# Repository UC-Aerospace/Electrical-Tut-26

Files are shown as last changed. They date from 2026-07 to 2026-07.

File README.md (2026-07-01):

# 2026 Avionics tutorial example boards!!
Here's where you'll find basic examples of a flight computer board using the RP2350 microcontroller. 

We have two different example sizes.  
  
(50mm x 50mm) This shows it's possible to design a 2-layer 50mm x 50mm board to fit the minimum rocket tube diameter of 50mm. Made by Grayson. This is the one we have ordered and will be avalible to pass around.  
  
~~(66mm x 66mm) This 2-layer example board is slightly bigger but small enough to fit in an L2 rocket. Made by Kaden.~~  
Unfortunatly this board has some issues at the moment, we might look into fixing it. Left for now as it shows a different general approach.

> [!NOTE]
> While making a 2-layer 50mm x 50mm board is possible, routing something this small can be quite a puzzle especially to do nicely. If you do target 50x50 we would reccomend a 4-layer board. Otherwise, we'd suggest something either 66x66mm or 88x88mm.

> [!CAUTION]
> We are not experts and are still all learning a lot ourselves. As such some of these designs may be suboptimal, don't take them as best practice. If you see an issue with any of the boards, or even just think you do, feel free to create an issue so we can all learn.

## Templates

These are barebones files to use as a starting point, and very simply include a board outline with holes that will match with our sleds, the RP2350 footprint and the Sense module footprint. Avalible in 50x50, 66x66 and 88x88 to modify as you wish.

## Resources / Datasheets
**_Please look_** at the datasheets for any major components you plan to use, e.g. (Voltage regulator, RP2350, Flash chip, Screen, LEDs, USB-C connector, etc..) They provide the information necessary to integrate them with your project and if any extra components are needed to work correctly.

The Raspberry Pi Foundation has provided a massive amount of technical information for the RP2350 microcontroller we use, so I'd suggest reviewing their datasheets to help build your boards!

[RP2350 Datasheet](https://datasheets.raspberrypi.com/rp2350/rp2350-datasheet.pdf)  
[RP2350 Hardware design examples](https://datasheets.raspberrypi.com/rp2350/hardware-design-with-rp2350.pdf)  
[Raspberry Pi Pico 2 datasheet](https://datasheets.raspberrypi.com/pico/pico-2-datasheet.pdf)
  
Also take a look at the sensor package used which we have got assembled for you:
[MicroSense](https://github.com/UC-Aerospace/Sense)

If you have any questions about the example board, then come talk to me!  
Happy making! :3


  
^ Demo flight computer, we will have a few to pass around.

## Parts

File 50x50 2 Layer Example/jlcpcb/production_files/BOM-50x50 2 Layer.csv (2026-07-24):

Comment | Designator | Footprint | LCSC | Quantity
0.25A | F1 | Fuse_0603_1608Metric | C151137 | 1
100 | R21,R22,R23 | C_0603_1608Metric_Pad1.08x0.95mm_HandSolder | C22775 | 3
100n | C1,C10,C13,C16,C17,C18,C19,C20,C21,C22,C23,C4,C5,C9 | C_0603_1608Metric_Pad1.08x0.95mm_HandSolder | C14663 | 14
10k | R7,R8 | R_0603_1608Metric_Pad0.98x0.95mm_HandSolder | C25804 | 2
10u | C24 | C_0805_2012Metric | C15850 | 1
12MHz | Y1 | Crystal_SMD_3225-4Pin_3.2x2.5mm_HandSoldering | C20625731 | 1
15p | C7,C8 | C_0603_1608Metric_Pad1.08x0.95mm_HandSolder | C1644 | 2
1k | R10,R13,R26,R27,R9 | R_0603_1608Metric_Pad0.98x0.95mm_HandSolder | C21190 | 5
1u | C2 | C_0603_1608Metric_Pad1.08x0.95mm_HandSolder | C15849 | 1
22u | C3,C6 | C_0805_2012Metric | C45783 | 2
27 | R14,R15 | R_0603_1608Metric_Pad0.98x0.95mm_HandSolder | C25190 | 2
3.3u | L1 | IND-SMD_L2.0-W1.6_AOTA-B201610S3R3-101-T | C42411119 | 1
33 | R12 | R_0603_1608Metric_Pad0.98x0.95mm_HandSolder | C23140 | 1
390 | R11 | C_0603_1608Metric_Pad1.08x0.95mm_HandSolder | C23151 | 1
4.7u | C11,C12,C14,C15 | C_0603_1608Metric_Pad1.08x0.95mm_HandSolder | C17673 | 4
4K7 | R17,R18,R19,R20 | C_0603_1608Metric_Pad1.08x0.95mm_HandSolder | C23162 | 4
560 | R4 | C_0603_1608Metric_Pad1.08x0.95mm_HandSolder | C23204 | 1
5k1 | R3,R6 | R_0603_1608Metric_Pad0.98x0.95mm_HandSolder | C27834 | 2
5k6 | R5 | C_0603_1608Metric_Pad1.08x0.95mm_HandSolder | C4382 | 1
820 | R2 | C_0603_1608Metric_Pad1.08x0.95mm_HandSolder | C23253 | 1
Buzzer | BZ3 | Buzzer_Murata_PKMCS0909E | C910763 | 1
Conn_01x02 | J1 | JST_XH_B2B-XH-A_1x02_P2.50mm_Vertical | C158012 | 1
Conn_01x03 | J3 | PinSocket_1x03_P2.54mm_Vertical | C146243 | 1
Conn_01x04 | J4 | PinSocket_1x04_P2.54mm_Vertical | C5116483 | 1
D_Schottky | D2 | D_SMA | C8678 | 1
Green LED | D10,D4,D5 | LED_0805_2012Metric | C2297 | 3
MMBT3904 | Q2 | SOT-23 | C7420353 | 1
ON_SW | SW4 | SW-TH_3P-L8.6-W4.5-P2.60 | C2857672 | 1
PWR_SELECT | SW1 | SW-TH_KH-SS22D07-VG4H | C5274482 | 1
RP2354_60QFN | U4 | QFN-60-1EP_7x7mm_P0.4mm_EP3.4x3.4mm_ThermalVias | C41378174 | 1
Red LED | D8 | LED_0805_2012Metric | C84256 | 1
SMAJ8.5A | D3 | D_SMA | C49424014 | 1
SW_Push | SW2,SW3 | SW_SPST_TS-1088-xR020 | C720477 | 2
USBLC6-2SC6 | U2 | SOT-23-6 | C7519 | 1
USB_C_Receptacle_USB2.0_14P | J2 | USB_C_Receptacle_GCT_USB4085 | C2988369 | 1
Voltage Regulator (MCP1755S-3302E/DB) | U3 | SOT-23-3 | C638611 | 1
W25Q32JVSSIQ | U1 | SOIC-8_5.3x5.3mm_P1.27mm | C179173 | 1
WS2812B | D6,D7 | LED_WS2812B_PLCC4_5.0x5.0mm_P3.2mm | C965555 | 2
Yellow LED | D1,D9 | LED_0805_2012Metric | C2296 | 2
Sensor Board | U5 | UCA_Sense |  | 1

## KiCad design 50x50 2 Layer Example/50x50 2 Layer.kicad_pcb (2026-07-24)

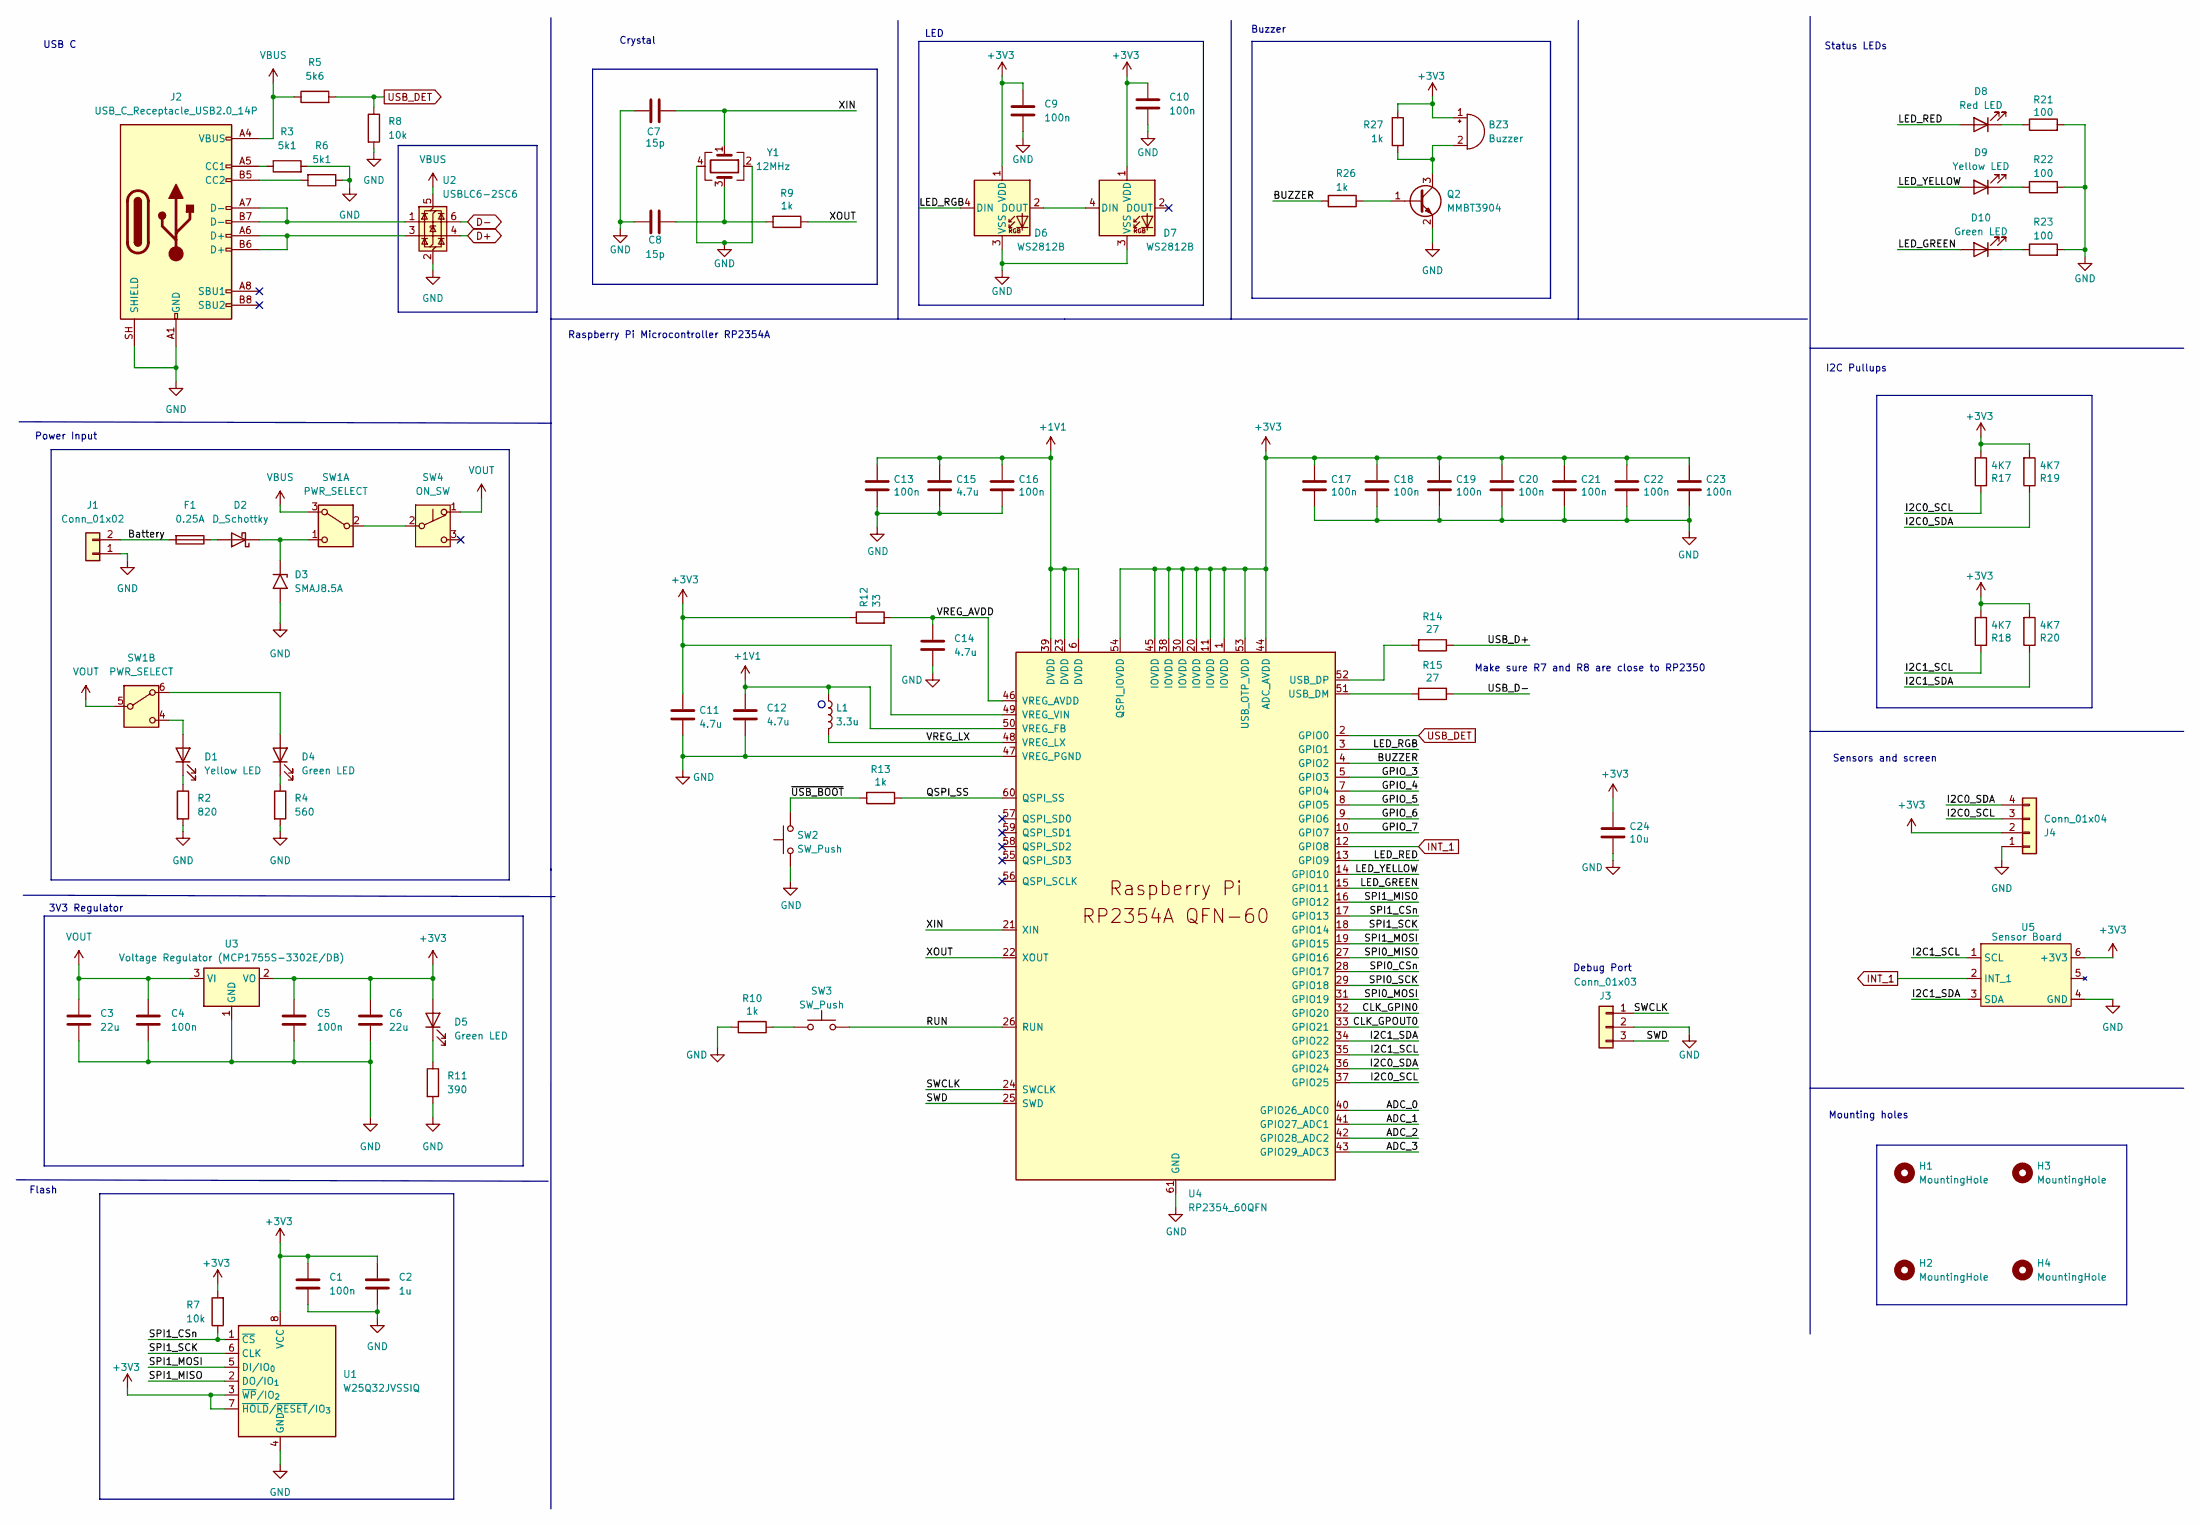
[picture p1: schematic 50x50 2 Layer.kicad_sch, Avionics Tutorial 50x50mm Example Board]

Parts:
BZ3: Buzzer; Buzzer_Murata_PKMCS0909E
C1, C4, C5, C9, C10: 100n; C_0603_1608Metric_Pad1.08x0.95mm_HandSolder; MPN CL21B104KCFNNNE; LCSC Part Number C28233
C2: 1u; C_0603_1608Metric_Pad1.08x0.95mm_HandSolder
C3, C6: 22u; C_0805_2012Metric; MPN CL21C200JBANNNC; LCSC Part Number C15850
C7, C8: 15p; C_0603_1608Metric_Pad1.08x0.95mm_HandSolder; MPN 0603N270J500CT; LCSC Part Number C1798
C11, C12, C14, C15: 4.7u; C_0603_1608Metric_Pad1.08x0.95mm_HandSolder
C13, C16, C17, C18, C19, C20, C21, C22, C23: 100n; C_0603_1608Metric_Pad1.08x0.95mm_HandSolder
C24: 10u; C_0805_2012Metric
D1: Yellow LED; LED_0805_2012Metric; MPN ORH-R36A; LCSC Part Number C205445
D2: D_Schottky; D_SMA; MPN SS34; LCSC Part Number C2909963
D3: SMAJ8.5A; D_SMA
D4: Green LED; LED_0805_2012Metric; MPN ORH-R36A; LCSC Part Number C205445
D5: Green LED; LED_0805_2012Metric; MPN NCD0603C1; LCSC Part Number C84264
D6, D7: WS2812B; LED_WS2812B_PLCC4_5.0x5.0mm_P3.2mm
D8: Red LED; LED_0805_2012Metric; MPN 16-213UYC/S530-A2/TR8; LCSC Part Number C136118
D9: Yellow LED; LED_0805_2012Metric; MPN 16-213SYGC/S530-E3/TR8; LCSC Part Number C264408
D10: Green LED; LED_0805_2012Metric; MPN 16-213SURC/S530-A4/TR8; LCSC Part Number C74339
F1: 0.25A; Fuse_0603_1608Metric; MPN 0467.250NRHF; LCSC Part Number C151137
H1, H2, H3, H4: MountingHole; MountingHole_3.2mm_M3
J1: Conn_01x02; JST_XH_B2B-XH-A_1x02_P2.50mm_Vertical; MPN B2B-XH-A(LF)(SN); LCSC Part Number C158012
J2: USB_C_Receptacle_USB2.0_14P; USB_C_Receptacle_GCT_USB4085; MPN GT-USB-7010ASV; LCSC Part Number C2988369
J3: Conn_01x03; PinSocket_1x03_P2.54mm_Vertical; MPN 2.54-1*3P; LCSC Part Number C146243
J4: Conn_01x04; PinSocket_1x04_P2.54mm_Vertical; MPN 2.54-1*4; LCSC Part Number C5116483
L1: 3.3u; IND-SMD_L2.0-W1.6_AOTA-B201610S3R3-101-T
Q2: MMBT3904; SOT-23
R2: 820; C_0603_1608Metric_Pad1.08x0.95mm_HandSolder; MPN RC0805FR-07470RL; LCSC Part Number C114564
R3, R6: 5k1; R_0603_1608Metric_Pad0.98x0.95mm_HandSolder; MPN 0805W8F5101T5E; LCSC Part Number C27834
R4: 560; C_0603_1608Metric_Pad1.08x0.95mm_HandSolder; MPN RC0805FR-07470RL; LCSC Part Number C114564
R5: 5k6; C_0603_1608Metric_Pad1.08x0.95mm_HandSolder; MPN 0805W8F5601T5E; LCSC Part Number C4382
R7: 10k; R_0603_1608Metric_Pad0.98x0.95mm_HandSolder
R8: 10k; R_0603_1608Metric_Pad0.98x0.95mm_HandSolder; MPN 0805W8F1002T5E; LCSC Part Number C17414
R9: 1k; R_0603_1608Metric_Pad0.98x0.95mm_HandSolder; MPN RC0805FR-074K7L; LCSC Part Number C17513
R10, R13: 1k; R_0603_1608Metric_Pad0.98x0.95mm_HandSolder
R11: 390; C_0603_1608Metric_Pad1.08x0.95mm_HandSolder; MPN RC0805JR-07360RL; LCSC Part Number C137444
R12: 33; R_0402_1005Metric
R14, R15: 27; R_0603_1608Metric_Pad0.98x0.95mm_HandSolder
R17, R18, R19, R20: 4K7; C_0603_1608Metric_Pad1.08x0.95mm_HandSolder; MPN RC0805FR-074K7L; LCSC Part Number C60816
R21, R22, R23: 100; C_0603_1608Metric_Pad1.08x0.95mm_HandSolder; MPN RC0805JR-07130RL; LCSC Part Number C137474
R26, R27: 1k; R_0603_1608Metric_Pad0.98x0.95mm_HandSolder; MPN RC0805FR-074K7L
SW1: PWR_SELECT; SW-TH_KH-SS22D07-VG4H
SW2, SW3: SW_Push; SW_SPST_TS-1088-xR020
SW4: ON_SW; SW-TH_3P-L8.6-W4.5-P2.60
U1: W25Q32JVSSIQ; SOIC-8_5.3x5.3mm_P1.27mm
U2: USBLC6-2SC6; SOT-23-6
U3: Voltage Regulator (MCP1755S-3302E/DB); SOT-23-3
U4: RP2354_60QFN; QFN-60-1EP_7x7mm_P0.4mm_EP3.4x3.4mm_ThermalVias
U5: Sensor Board; UCA_Sense
Y1: 12MHz; Crystal_SMD_3225-4Pin_3.2x2.5mm_HandSoldering; MPN ABM8-272-T3; LCSC Part Number C20625731

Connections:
+1V1: C12.1, C13.1, C15.1, C16.1, L1.1, U4.6 (DVDD), U4.23 (DVDD), U4.39 (DVDD), U4.50 (VREG_FB)
+3V3: BZ3.1 (+), C1.1, C2.1, C5.1, C6.1, C9.1, C10.1, C11.1, C17.1, C18.1, C19.1, C20.1, C21.1, C22.1, C23.1, C24.1, D5.2 (A), D6.1 (VDD), D7.1 (VDD), J4.2, R7.2, R12.1, R17.2, R18.2, R19.2, R20.2, R27.1, U1.3 (~WP/IO_{2}), U1.7 (~HOLD/~RESET/IO_{3}), U1.8 (VCC), U3.2 (VO), U4.1 (IOVDD), U4.11 (IOVDD), U4.20 (IOVDD), U4.30 (IOVDD), U4.38 (IOVDD), U4.44 (ADC_AVDD), U4.45 (IOVDD), U4.49 (VREG_VIN), U4.53 (USB_OTP_VDD), U4.54 (QSPI_IOVDD), U5.6 (+3V3)
/ADC_0: U4.40 (GPIO26_ADC0)
/ADC_1: U4.41 (GPIO27_ADC1)
/ADC_2: U4.42 (GPIO28_ADC2)
/ADC_3: U4.43 (GPIO29_ADC3)
/BUZZER: R26.2, U4.4 (GPIO2)
/Battery: F1.2, J1.2
/CLK_GPIN0: U4.32 (GPIO20)
/CLK_GPOUT0: U4.33 (GPIO21)
/GPIO_3: U4.5 (GPIO3)
/GPIO_4: U4.7 (GPIO4)
/GPIO_5: U4.8 (GPIO5)
/GPIO_6: U4.9 (GPIO6)
/GPIO_7: U4.10 (GPIO7)
/I2C0_SCL: J4.3, R17.1, U4.37 (GPIO25)
/I2C0_SDA: J4.4, R19.1, U4.36 (GPIO24)
/I2C1_SCL: R18.1, U4.35 (GPIO23), U5.1 (SCL)
/I2C1_SDA: R20.1, U4.34 (GPIO22), U5.3 (SDA)
/LED_GREEN: D10.2 (A), U4.15 (GPIO11)
/LED_RED: D8.2 (A), U4.13 (GPIO9)
/LED_RGB: D6.4 (DIN), U4.3 (GPIO1)
/LED_YELLOW: D9.2 (A), U4.14 (GPIO10)
/QSPI_SS: R13.1, U4.60 (QSPI_SS)
/RUN: SW3.2, U4.26 (RUN)
/SPI0_CSn: U4.28 (GPIO17)
/SPI0_MISO: U4.27 (GPIO16)
/SPI0_MOSI: U4.31 (GPIO19)
/SPI0_SCK: U4.29 (GPIO18)
/SPI1_CSn: R7.1, U1.1 (~CS), U4.17 (GPIO13)
/SPI1_MISO: U1.2 (DO/IO_{1}), U4.16 (GPIO12)
/SPI1_MOSI: U1.5 (DI/IO_{0}), U4.19 (GPIO15)
/SPI1_SCK: U1.6 (CLK), U4.18 (GPIO14)
/SWCLK: J3.1, U4.24 (SWCLK)
/SWD: J3.3, U4.25 (SWD)
/USB_D+: R14.1
/USB_D-: R15.1
/VREG_AVDD: C14.1, R12.2, U4.46 (VREG_AVDD)
/VREG_LX: L1.2, U4.48 (VREG_LX)
/XIN: C7.1, U4.21 (XIN), Y1.1
/XOUT: R9.1, U4.22 (XOUT)
/~USB_BOOT: R13.2, SW2.2
D+: U2.4 (I/O2)
D-: U2.6 (I/O1)
GND: C1.2, C2.2, C3.2, C4.2, C5.2, C6.2, C7.2, C8.2, C9.2, C10.2, C11.2, C12.2, C13.2, C14.2, C15.2, C16.2, C17.2, C18.2, C19.2, C20.2, C21.2, C22.2, C23.2, C24.2, D3.2 (A2), D6.3 (VSS), D7.3 (VSS), J1.1, J2.A1 (GND), J2.A12 (GND), J2.B1 (GND), J2.B12 (GND), J2.SH (SHIELD), J3.2, J4.1, Q2.2 (E), R2.2, R3.2, R4.2, R6.1, R8.2, R10.2, R11.2, R21.2, R22.2, R23.2, SW2.1, U1.4 (GND), U2.2 (GND), U3.1 (GND), U4.47 (VREG_PGND), U4.61 (GND), U5.4 (GND), Y1.2, Y1.4
INT_1: U4.12 (GPIO8), U5.2 (INT_1)
unnamed: BZ3.2 (-), Q2.3 (C), R27.2
unnamed: C8.1, R9.2, Y1.3
unnamed: D1.2 (A), SW1.4 (A)
unnamed: D1.1 (K), R2.1
unnamed: D2.2 (A), F1.1
unnamed: D2.1 (K), D3.1 (A1), SW1.1 (A)
unnamed: D4.2 (A), SW1.6 (C)
unnamed: D4.1 (K), R4.1
unnamed: D5.1 (K), R11.1
unnamed: D6.2 (DOUT), D7.4 (DIN)
unnamed: D8.1 (K), R21.1
unnamed: D9.1 (K), R22.1
unnamed: D10.1 (K), R23.1
unnamed: J2.A5 (CC1), R3.1
unnamed: J2.B5 (CC2), R6.2
unnamed: J2.A6 (D+), J2.B6 (D+), U2.3 (I/O2)
unnamed: J2.A7 (D-), J2.B7 (D-), U2.1 (I/O1)
unnamed: Q2.1 (B), R26.1
unnamed: R10.1, SW3.1
unnamed: SW1.2 (B), SW4.2 (B)
unnamed: R15.2, U4.51 (USB_DM)
unnamed: R14.2, U4.52 (USB_DP)
USB_DET: R5.2, R8.1, U4.2 (GPIO0)
VBUS: J2.A4 (VBUS), J2.A9 (VBUS), J2.B4 (VBUS), J2.B9 (VBUS), R5.1, SW1.3 (C), U2.5 (VBUS)
VOUT: C3.1, C4.1, SW1.5 (B), SW4.1 (A), U3.3 (VI)

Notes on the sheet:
Sensors and screen
Debug Port
Raspberry Pi Microcontroller RP2354A
Mounting holes
Buzzer
Crystal
Make sure R7 and R8 are close to RP2350
I2C Pullups
3V3 Regulator
Power Input
Flash
USB C
LED
Status LEDs

Board: 2 copper layers, 79 parts (0 on the bottom side), 52 nets, no tracks yet.

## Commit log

2026-07-01 Tidy up for 2026: remove backup files, update README year
    Remove stale .kicad_sch_old and .bak files; add them to .gitignore
    alongside .claude/ so they stay out in future. Update title year to 2026.
2026-07-07 Rework power input switching and protection
    - Replace diode-OR with DPDT source select (VBUS/battery) plus
    separate on/off switch
    - Add SMAJ8.5A TVS on the battery input
    - Add per-source indicator LEDs, 820R battery / 560R USB
    [50x50 2 Layer.kicad_pcb, 50x50 2 Layer.kicad_sch]
2026-07-13 Updated Schematic to reflects changes to the 2026 Flight Computer
    Updates:
    MCU (RP2354A)
    Voltage Regulator
    Bypass/ Decoupling Capacitors
    USB C
    Crystal
    Flash
    Reset Button
    Debug Port
    LED
    Buzzer
    Status LEDs
    [50x50 2 Layer.kicad_sch]
2026-07-16 Minor changes to Schematic
    Adjusted green sections and added Footprints
    [50x50 2 Layer.kicad_sch]
2026-07-18 Minor changes and moving things around
    [50x50 2 Layer.kicad_sch]
2026-07-19 Added Footprints
    Added footprints for the Buzzer, 3.3uH Inductor, and the SPDT Power Switches
    [50x50 2 Layer.kicad_sch]
2026-07-20 Light changes to GPIO connection names
    [50x50 2 Layer.kicad_sch]
2026-07-23 Added Footprint for new Switches Attached LCSC numbers to components Started Cost Optimisation
    [50x50 2 Layer-CuBottom.gbr, 50x50 2 Layer-CuTop.gbr, 50x50 2 Layer-EdgeCuts.gbr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]
2026-07-24 Updated Inductor
    [50x50 2 Layer.kicad_pcb]
2026-07-24 Fixed RP2354A Schematic Added LCSC Part Numbers Added Datasheets
    [50x50 2 Layer-CuBottom.gbr, 50x50 2 Layer-CuTop.gbr, 50x50 2 Layer-EdgeCuts.gbr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]
2026-07-24 Minor changes to Schematic
    Adjusted some of the labels, specifically for D- and D+ connected to the USB C
    Moved Debug Port and Reset Button back to their own sections
    [50x50 2 Layer.kicad_sch]
